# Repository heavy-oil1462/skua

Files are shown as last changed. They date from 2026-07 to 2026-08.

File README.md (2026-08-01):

# Skua

A wind-driven gull scarer for a boat, named for the bird that chases
gulls away. A 1.2 m rotor of flapping plastic flags spins on a
plank-mounted bearing tower; the motion and the clatter keep gulls off.
No electronics, no motor — wind only.

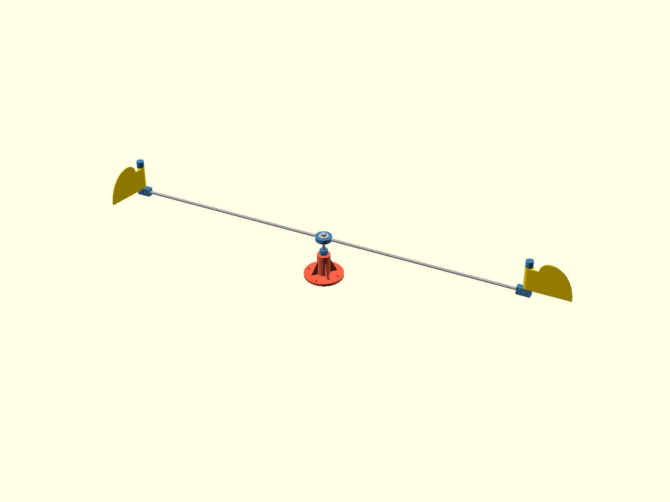
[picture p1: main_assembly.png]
assembly


## How it works

Each vane is a flag on a VERTICAL hinge: a sleeve spinning on a short
vertical stub rod, held at the arm tip by a printed knuckle bracket,
with the panel reaching out sideways like a door. The end cap's stop
wedge rides in a notch in the sleeve's top end and is the vane's only
stop; below, the sleeve rests on a thin PTFE washer on the bracket's
flat top, the vane's whole thrust seat: bought, slippery where a
printed seat drags, and the cheapest wear part there is. The
vane swings freely through about 90 degrees one way and hits the
hard stop the other way, the impact landing flat on the notch walls.
The cap is a clamp, so the driven-stop angle is set, and re-set, by
loosening two bolts — the field-testing knob. The swing angle is the
sleeve notch minus the wedge width, so trying a different swing is a
reprint of two small caps; the vanes do not change. Wind pushing a
vane onto its stop gets the full panel face and drags the rotor
around; wind pushing the other vane (coming back upwind) just
weathervanes it flat. Set both caps the same way around seen from
above so the torques add and the rotor self-starts in any wind
direction. Every pass the driving vane bangs against its stop — free
percussion.

The flag itself is built for the return trip, not the push: catching
wind is the easy half, the swing back to the driven stop is the
fight. So the panel is a thin arched pennant: it spans the sleeve,
runs flat a short shoulder past the sleeve top, rises in a quarter
circle to the arch peak, then sweeps down to the bottom outer tip.
It is a bare 2 mm skin with no stiffening rim, weight being what
the return swing pays for; if a flag ever creep-curls in the sun,
that is the sign to reprint with a slim rim on the arch edge.
Height is free for the
swing mechanics (only the spread over reach enters the hinge
integrals), so the raised arch carries face area near the hinge
where folding wants it, while the shortened reach keeps the tip
inertia the return swing hates low. Compared to the old full
rectangle the hinge inertia drops by more than half and the flappy
free top corner is gone. Nothing of the flag sits close to the end
cap, so the cap's bolt hardware clears the fold at any cap angle.

The hinge being vertical is what makes it start in light wind: folding
never lifts any weight. A vane hanging from a horizontal hinge only
folds when wind pressure beats its weight, roughly a moderate breeze
for printed plastic, and below that both vanes present the same face
and the rotor just rocks. On vertical hinges the returning flag
weathervanes at a whisper, so the asymmetry, and the spin, are there
from the first puff.

The rotor rides on two 608 skateboard bearings spaced 45 mm apart in the
base tower, so the 1.2 m span runs true. All rotating weight hangs on a
collar clamped to the shaft, resting on the top bearing's inner race.

There is also an OPTIONAL uplift retainer: a smaller single-bolt collar
clamped under the bottom bearing, a millimeter clear of its inner race,
living in a cavity inside the base tower. It carries nothing while the
rotor runs, but a wave slam or a gust that unloads the rotor cannot
lift the shaft out of its bearings, and it keeps the bottom bearing
captive. In practice the rotor's weight alone keeps the shaft seated
in all ordinary conditions, so most builds can leave the retainer out;
the shaft is the same length either way, the tip just rides loose in
the cavity, and one can be printed and retrofitted through the open
cavity later if the mooring proves rough (see the assembly guide).

## Bill of materials

- printed: 1 base, 2 hub shells (one part printed twice; they close
  seats to seats over the arms), 2 vanes, 2 tip bracket peg halves +
  2 plain halves (each arm tip clamps between one of each), 2 end
  caps, 1 thrust collar, and optionally 1 retainer collar (see
  `stl/`). Plus one bench tool: 2 die jig halves (again one part
  printed twice), soft vice jaws that hold the shaft for the die
  pass without the vice teeth marking it
- filament: something UV-stable (ASA) for a machine that lives on a
  boat; PLA is fine for prototyping and fit checks but creeps under
  clamp preload and degrades in the sun
- 2x 608 bearing (8x22x7 — any skateboard bearing, shielded preferred)
- 8 mm aluminum rod: 1x 145 mm (shaft), 2x 600 mm (arms), 2x 112 mm
  (the vertical hinge stubs). The arm diameter is a parameter
  (`arm_rod_d`, default 8): thinner arms save weight and the hub
  seats and bracket grooves follow, but re-gauge the arm fit on the
  new stock and let the storm gate judge the arm, which is the
  machine's structural fuse
- 2x PTFE washer 8x14x1 (the vane thrust seats: each sleeve spins on
  one, resting on the bracket's flat top)
- 2x M8 nyloc + 2x M8 fender washer (8.4x30x1.5): the hub clamp.
  The shaft's top end is threaded M8x1.25 for 35 mm with a hand die
  (8 mm rod is an M8 blank; the die self-aligns and nothing is
  drilled), and the washers press the shell sandwich together from
  either end
- 8x M3x25 bolt + nyloc + 1 small washer each (the tip bracket
  clamshells, kept light because they ride at the arm tips; the
  nylocs sit captive in hex pockets, so a screwdriver on the head
  side is the whole tool kit. M3x30s also fit, standing about 5 mm
  proud)
- 6x M3x16 bolt + nyloc (two each for the dual-bolt clamps: the
  thrust collar and 2 caps), plus one more if the retainer is fitted
- 4x 4.2 mm wood screws, and a plank to screw the base onto (any
  thickness, no hole: nothing reaches below the base)

## Calibration before printing the real parts

Printers and filaments vary; the three fits are measured, not guessed.
They are specific to the printer, the slicing profile, AND the
filament: gauges sliced with a different nozzle profile or printed in
a different material do not transfer, so prototyping in PLA and then
building the real machine in ASA means running the gauges again in
ASA with the production profile.

1. Print `stl/bearing_pocket_gauge.stl`, press a bearing into each ring,
   put the number of the firm-but-not-brutal one into `bearing_press_d`
   in `cad/design_params.scad`.
2. Print `stl/rod_fit_gauge.stl`, push the rod through the holes. The
   one it presses into firmly is `rod_snug_d`; the smallest one it spins
   in without grabbing is `rod_free_d`.
3. `python3 scripts/regen_all.py` and print the real parts.

## Assembly

Step-by-step guide with rendered images: [docs/assembly.md](docs/assembly.md).
The short version: bearings pressed into the base; the shaft top
die-threaded (the printed die jig holds it in the vice), then the
hub sandwich built up the thread (nut, washer, shell, arms, shell,
washer, nut), plus the optional retainer clamped flush with the
shaft tip if fitted; the base slid onto the shaft from the tip end,
the thrust collar gauged a millimeter off the top race and clamped,
then everything flipped upright and the base screwed down; the tip
bracket clamshells bolted over arms and stubs, washers, sleeves and
caps slid on, and each cap rotated to its driven-stop angle, both
the same way around, and clamped.
Nothing is drilled anywhere, not the rods, not
the printed parts, not even the plank, and no joint is permanent:
the hub is a washer-clamped sandwich, the tip brackets are
clamshells, everything else is a slit clamp, so every position and
stop angle can be reset by loosening a bolt or two.
Re-torque the clamps at the start of each season, printed plastic
relaxes.

## Alternative versions

Everything above is the default machine, and it is complete as
described. Two alternatives live in the repo, kept current but out
of the main path:

- Hub clamshell (`stl/hub_front.stl` + `stl/hub_back.stl`, plus 5x
  M5x35 bolt + nyloc + 2 wide washers each, replacing the M8 stack
  and the die pass): the pre-sandwich hub, a clamshell that closes
  over shaft and arms and bolts shut. It needs no rod prep at all,
  which is the one reason to choose it; the price is about 80 g and
  three bolts' worth of hardware, and it carries the arms about
  30 mm higher on the same shaft.
- The tri variant ([docs/tri_concept.md](docs/tri_concept.md)): the
  three-arm light-wind sibling of this machine, a parallel line
  with its own release tags (tri-vX.Y), not a successor. It prints
  this exact vane assembly a third time and swaps only the hub for
  a wider three-seat version of the same shell sandwich; `cad/tri/`
  is its home while it matures, and nothing there changes the
  machine on this page.

## Working on the design

CAD is OpenSCAD, rendered headlessly through nix; derived artifacts are
regenerated by one command and gated before commit:

- `python3 scripts/regen_all.py` after any .scad change
- `python3 scripts/regen_all.py --check` before any commit

The gates cover interface dimensions (`check_params.py`), the assembly
stack-up (`geometry_check.py`), and performance (`performance_check.py`:
the wind speed the rotor spins up at, a parasitic drag ratchet, and
storm-case safety factors for every load path). CI runs the same
command, so a change that would not fit, not start, or not survive
does not merge.

See `CLAUDE.md` for the full workflow and design rules.

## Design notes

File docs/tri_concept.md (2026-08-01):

# The tri variant: consistent spin in the least wind

Skua ships in two parallel variants, each with its own release line
tagged on main:

- the DUAL: two arms, solid vanes, the mature machine (v1.0 at tag
  time). Its docs are the README and the assembly guide.
- the TRI: three arms, the light-wind variant, young (tri-v0.1
  when it first flies). This document and `cad/tri/` are its home
  while it grows; it is a sibling of the dual, not its successor,
  and both live on.

Status: concept study. Nothing under `cad/tri/` changes dual parts,
parameters or gates, and nothing from it is exported to `stl/`.

One constraint carries over from the dual: the overall span stays
close to today's sweep circle, so when vane reach grows the arms
shorten to match. Everything else is open.

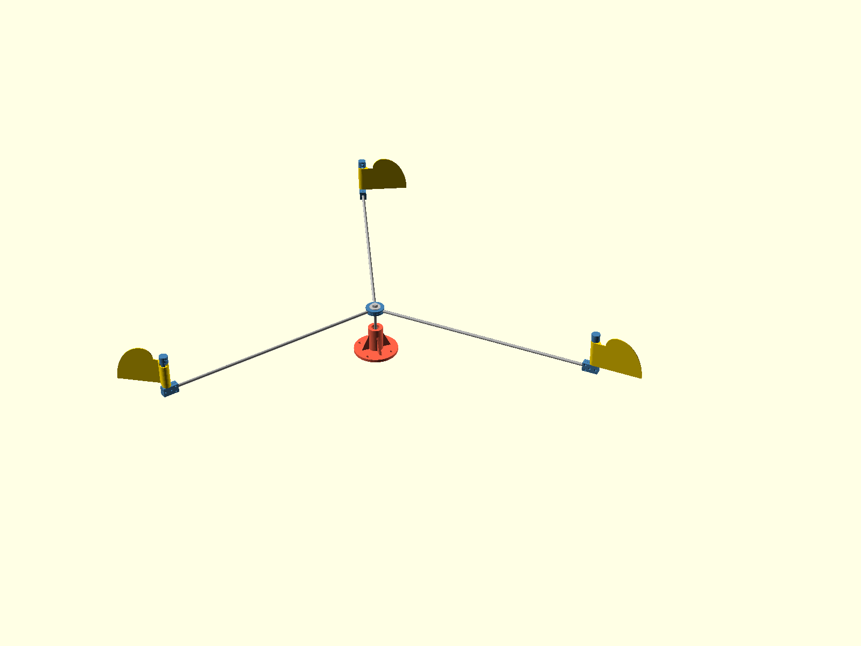
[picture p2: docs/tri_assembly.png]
tri concept


The scene is `cad/tri/tri_assembly.scad`; open it in OpenSCAD to
walk around it (regen_all renders it to the image above). It shows
the tri as currently planned: the ENTIRE vane assembly, tip
bracket, stub, PTFE thrust washer, vane and cap-wedge stop, is the
dual's verbatim, printed and bought once more per extra arm. Only
the hub is the tri's own (its wider washer-jaw sizing lives in
`tri_` prefixed parameters), and nothing from `cad/tri/` is
exported to `stl/`.

The recipe is deliberately minimal: the only new joint is the hub,
and the only rod prep in the whole machine is one M8x1.25 die pass
on the shaft's top end (8 mm rod is an M8 blank, so a hand die
self-aligns; no drilling, no taps, no lathe). A third vane-arm set
from the dual's own STLs plus the hub hardware turn dual spares
into a tri rotor, and every spare fits both machines.

## The washer-jaw hub

The hub is the shell sandwich (`tri_hub_shell` in
`cad/tri/tri_hub.scad`, the one in the scene): the same design the
dual runs as its default hub (`cad/hub_shell.scad`), sized for
three seats at 120 degrees, so the one hub design serves both
machines the way the one vane assembly does. Two identical thin
half-shells, each a half-round seat over a web, cradle the arms
over the full grip; the arms butt the boss circle and stand proud
of the mating faces by half the clamp gap, and two large M8 fender
washers press the sandwich together, clamped by M8 nylocs on the
shaft's die-threaded top end (8 mm rod is exactly an M8 thread
blank, so a hand die self-aligns and this rod is never drilled at
all; the lower nut is the shoulder, run to the die's thread
runout, and the upper one is the clamp). The arms get distributed
bearing top and bottom, nothing can rattle, and field seasons on
the dual proved the design out. The webs put a little plastic in
the clamp path, so the hub nuts join the seasonal re-torque round.

An alternative sits alongside it in the same file
(`tri_hub_disc`): ONE printed spacer disc, thinner than the rod,
three full-height slots keying the arms, the fender washers
pressing directly onto the rods from either side. Its load path is
worth stating: steel washer, aluminum rod, steel washer, steel
nut. No plastic sits in compression anywhere in that joint, so
unlike every clamp on the dual it does not relax and never needs
the seasonal re-torque; the price is that the washer rims
edge-clamp the arms instead of cradling them, and the slot flanks
alone carry the arms' horizontal storm bending. Same hardware,
one part instead of two, 7 mm tall against 13. The sandwich is the
default; the disc stays modeled for an A/B on the water if the
re-torque round ever grates.

A structural note, recording a correction: an earlier pass
rejected male thread on the shaft, claiming the storm case fails
at the threaded exit with a safety factor near 0.7. That number
was wrong, it borrowed the ARM's root moment (about 5.8 Nm). The
shaft at the hub only carries the vane drag over the short lever
down to the top bearing, about 1 Nm at survival wind, so even on
the M8 minor section the stress is about 42 MPa against the
alloy's 160: a storm factor near four, with gust amplitudes far
below fatigue concern. The storm-critical member is and remains
the arm, unaffected by any hub choice.

Sourcing notes for the prepared rods, kept from earlier rounds:

- Tube cannot be tapped: any 8 mm tube has a bore at or above 5
  mm, already larger than the M5 thread. Solid rod only.
- Solid 8 mm rod taps easily by hand (center punch, drill 4.2 mm
  about 14 mm deep, tap M5x0.8), and dies easily by hand (chamfer
  the end, run the die). Concentricity is not critical in either
  case, because bores and steps locate the rods and the threads
  only supply axial preload.
- For kits, linear-motion suppliers sell ground 8 mm shafts with
  threaded ends as a standard catalog option, which is zero
  machining.

## Dropped directions, recorded so they stay dropped

The tri once carried its own vane-assembly variants: a keyed stop
ring with a fin (angle baked into a bracket pocket, no
set-at-assembly step), a wedge-free clamp cap, a bottom-notched
vane, and a deferred screwed-stub tip (stubs tapped both ends,
pulled home by M5s, the direction a commercial kit might take).
All of it was deleted when the tri adopted the dual's vane
assembly wholesale. The reasons, so nobody re-derives the parts:
one part set now serves both machines (every printed spare fits
either rotor), the taps stay out of the toolchain, and the dual's
field seasons showed the adjustable cap stop is the knob you
actually want on the water, worth its price of hand-setting the
caps to a common sense — a price the tri pays once more per extra
arm. The keyed-stop idea itself was sound and lives in git
history if a kit round ever wants it back.

What the tri needs, beyond printed parts and rod stock: the hub's
two M8 nylocs with fender washers, and the dual's own tip
hardware three times over (four M3x25 per bracket clamshell, two
M3x16 per cap, two more at the thrust collar). Rod prep is the
single die pass on the shaft. The arms butt the hub's boss
circle; the set-by-hand joints are the gauged thrust collar and
the three cap wedges, same sense seen from above so the torques
add.

The dual's performance work showed what limits low-wind running
once the geometry is tuned: thrust-seat friction, vane mass, and
the two-arm torque gap. `scripts/tri_study.py` models the candidate
fixes as a cumulative ladder; run it for current numbers. The
directional findings:

- The worst parking angle of the two-arm rotor produces NEGATIVE
  torque (the wind holds it against rotation), which is the rocking
  behavior seen at low wind. Three arms at 120 degrees turn the
  worst angle into about 0.7 of mean torque; this is the single
  biggest consistency change and needs a new hub, a third arm and a
  third vane, nothing else.
- The PTFE thrust washer, once a tri ladder rung, is the dual's
  own baseline seat now. Film-and-frame vanes (printed perimeter,
  mylar or ripstop skin, ~28 g against 78) are the next real rung:
  they cut self-start sharply and also fix the re-arm margin (run
  the study for current numbers).
- Holding the span while trading arm length for vane reach (500 mm
  arms, 250 mm reach) needs 10 mm arm rod, abandoning the dual's
  one-rod-stock rule, and lands self-start around 0.26 m/s with a
  better storm margin than the dual has today.
- A meter more tower height is worth about ten percent of wind at
  threshold from the boundary layer alone.

Rejected endpoint, recorded so it is not rediscovered: cup or
Savonius geometry spins earliest of all but loses the flapping and
the clack that actually scare gulls; a rotation-driven clacker
would have to be bolted on, at which point the swing-vane concept
is the simpler machine.

Build order as the tri matures toward its first release: three
arms first via the washer-jaw hub above (pure consistency, dual
vanes throughout), then washers, then film vanes, then the
reach-for-arm trade only if the water still asks for it. Further
tri ideas land here as they come.

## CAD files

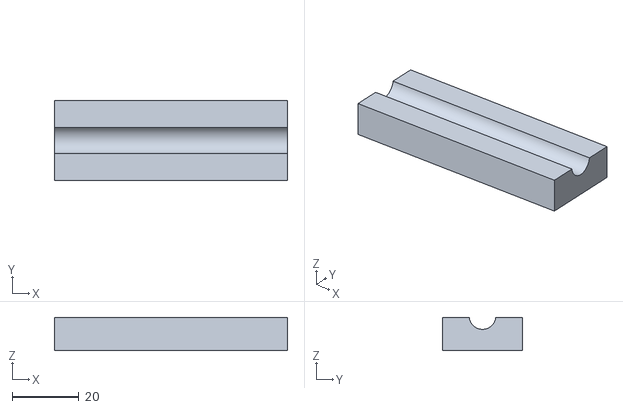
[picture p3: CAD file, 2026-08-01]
stl/die_jig.stl
70.0 x 24.0 x 10.0

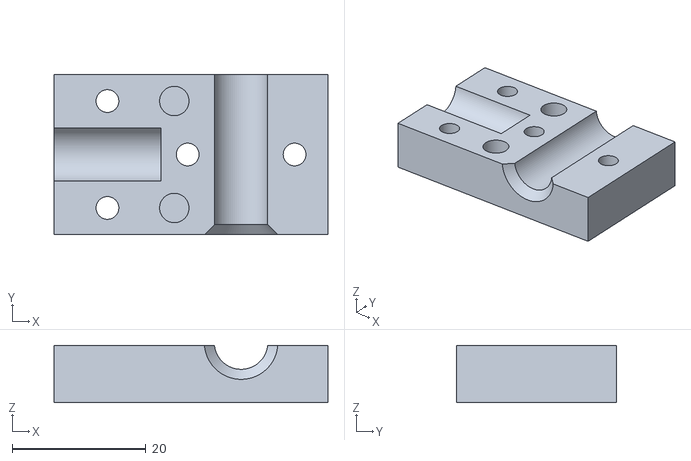
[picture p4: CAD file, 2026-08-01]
stl/bracket_plain_half.stl
41.0 x 24.0 x 8.60

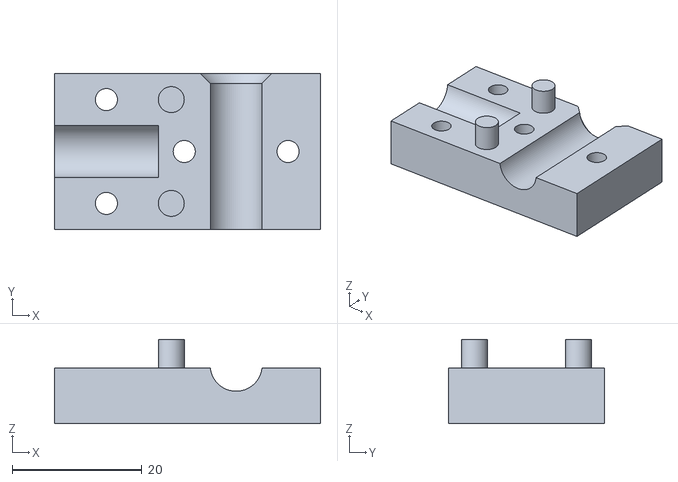
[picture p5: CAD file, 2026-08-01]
stl/bracket_peg_half.stl
41.0 x 24.0 x 13.0

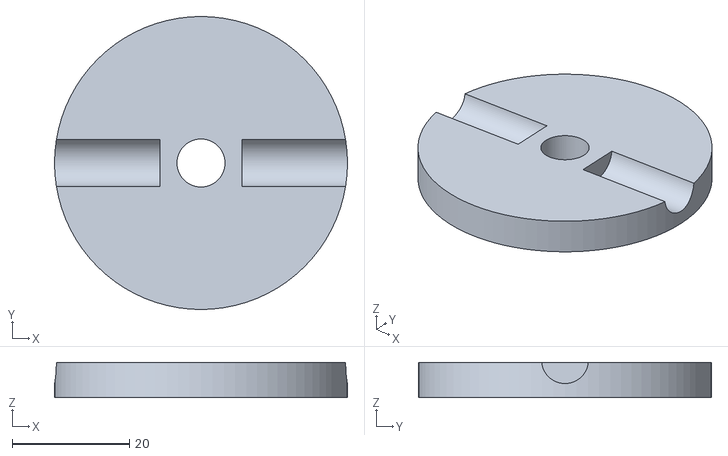
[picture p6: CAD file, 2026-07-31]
stl/hub_shell.stl
50.0 x 50.0 x 6.00

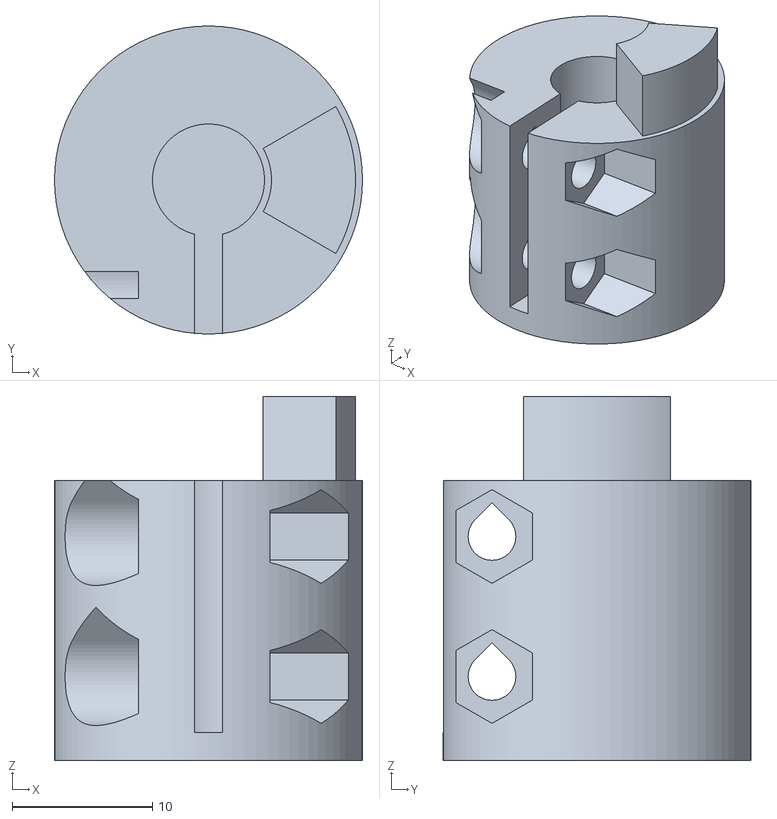
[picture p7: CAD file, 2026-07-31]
stl/end_cap.stl
22.0 x 22.0 x 26.0

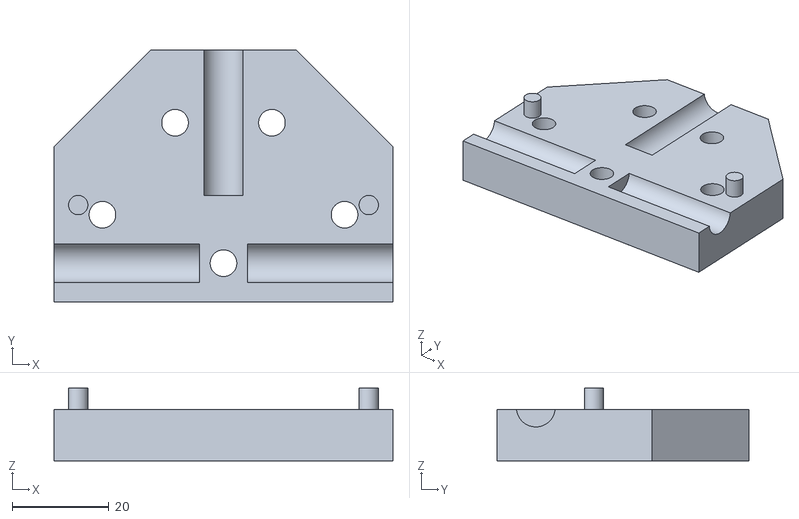
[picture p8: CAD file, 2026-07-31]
stl/hub_front.stl
70.0 x 52.0 x 15.0

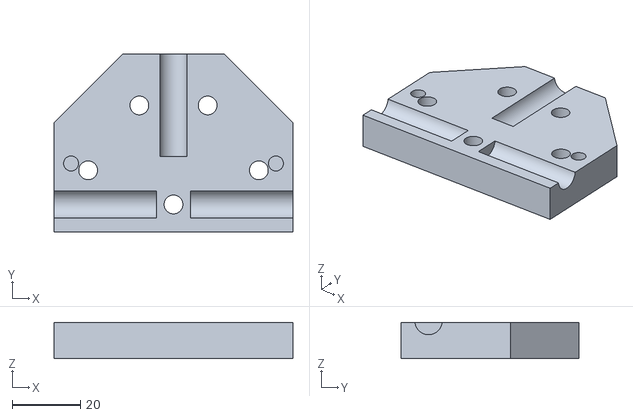
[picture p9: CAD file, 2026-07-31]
stl/hub_back.stl
70.0 x 52.0 x 10.6

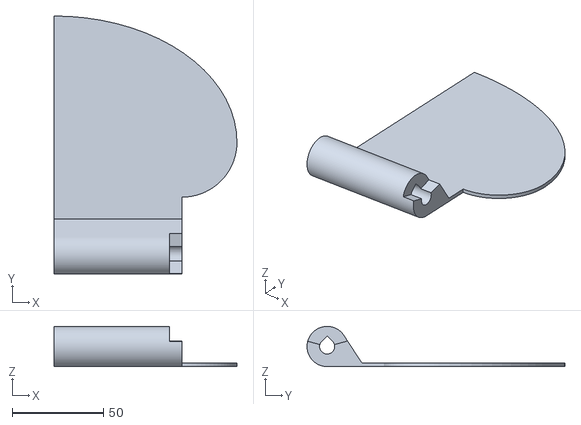
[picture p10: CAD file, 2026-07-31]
stl/vane.stl
100.0 x 141.0 x 22.0

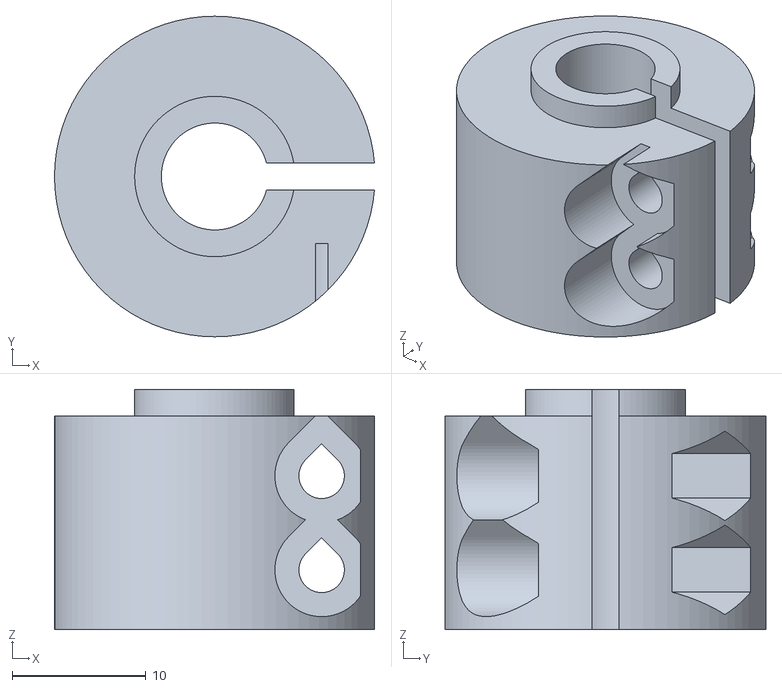
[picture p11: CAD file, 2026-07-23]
stl/collar.stl
24.0 x 24.0 x 18.0

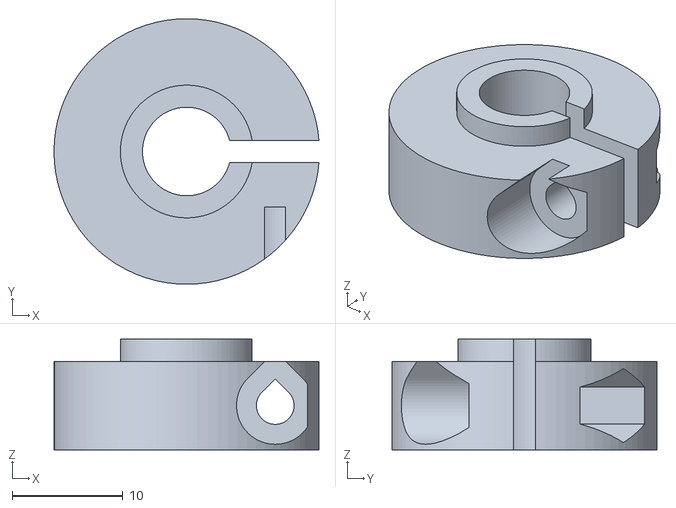
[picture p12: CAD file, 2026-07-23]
stl/retainer.stl
24.0 x 24.0 x 10.0

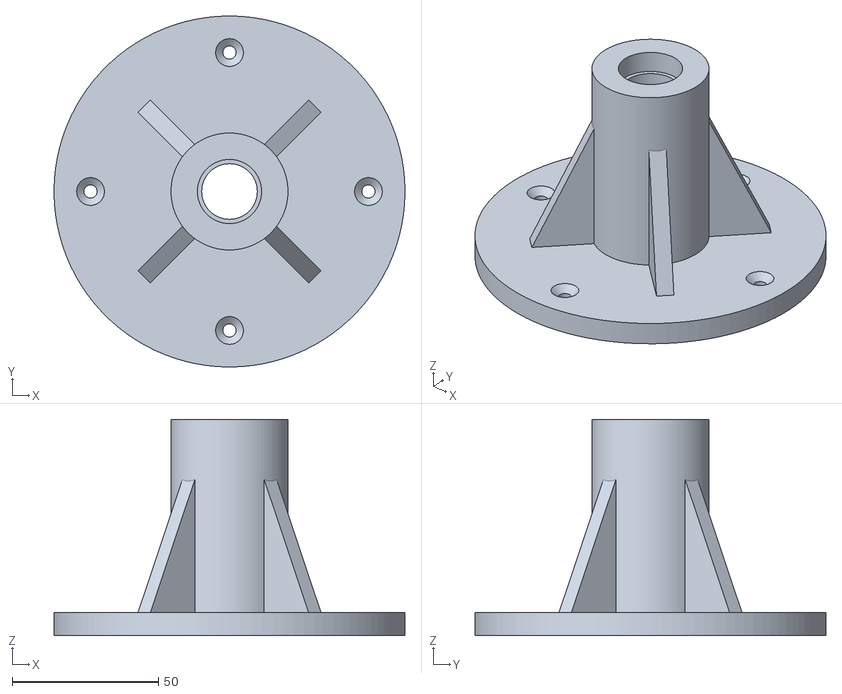
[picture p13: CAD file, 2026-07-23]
stl/base.stl
120.0 x 120.0 x 74.0

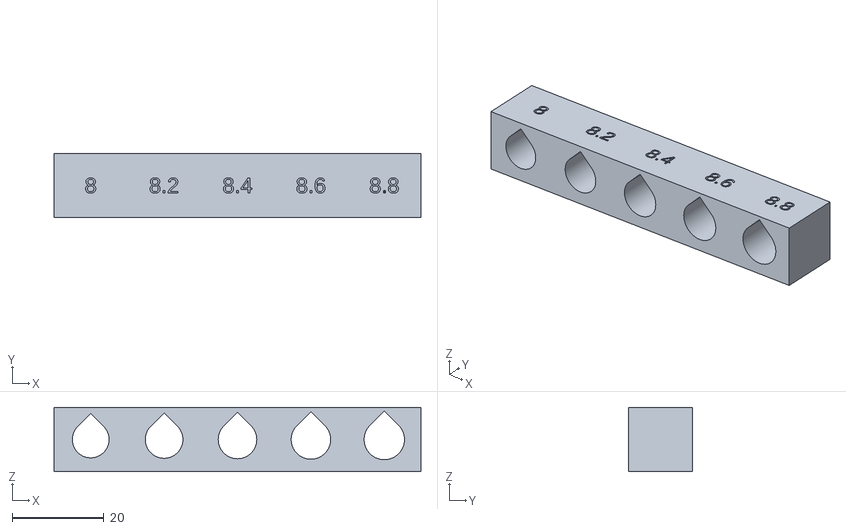
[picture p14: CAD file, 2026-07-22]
stl/rod_fit_gauge.stl
80.0 x 14.0 x 14.0

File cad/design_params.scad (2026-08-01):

// ============================================================
// SKUA SHARED DESIGN PARAMETERS — single source of truth for
// every dimension two parts must agree on.
//
// Consumers:
//   - every part in cad/ does        include <design_params.scad>
//   - parts in cad/calibration/ do   include <../design_params.scad>
//   - scripts/check_params.py FAILS the build if any of these names
//     is re-declared anywhere else — change values HERE only.
//
// Keep this file to simple `name = value;` lines so the tooling can
// parse it. One-off experiments: `openscad -D name=value` beats the
// include, no need to edit this file.
// ============================================================

// --- Aluminum rod stock (bought) ---
// 8 mm rod matches the 608 bearing bore, so shaft and stubs are
// PINNED to it (and the hub disc variant's M8 die pass rides on it).
// The arms default to the same stock but have their own knob below:
// thinner arms are a weight experiment, and the storm gate decides
// (the arm is the machine's fuse — watch its SF when thinning).
rod_d        = 8;
arm_rod_d    = 8;    // the two horizontal arms ONLY. Changing it
                     // (say to 6) resizes the hub shell seats and
                     // the bracket arm grooves; re-gauge arm_snug_d
                     // on the new stock first (the rod fit gauge
                     // grows a second bar when this differs from
                     // rod_d; the seat depth follows the gauged fit,
                     // and geometry_check gates the shell web left
                     // under it)
shaft_length = 145;  // vertical shaft; sets how high the rotor rides.
                     // Long enough that the hanging vanes clear the
                     // plank (geometry_check.py gates the clearance)
                     // and that the tip reaches down through the
                     // uplift retainer inside the base cavity.
arm_length   = 600;  // each horizontal arm (two of them)
stub_length  = 112;  // the vertical hinge rod at each arm tip (two of
                     // them, same stock): clamped through the tip
                     // bracket, carrying the vane sleeve and its cap
                     // (112 since the sleeve seat became the 1 mm PTFE
                     // washer; the old ring boss stood 2 mm)

// --- 608 skateboard bearing (bought, TWO of them) ---
// Two bearings spaced apart in the base tower instead of one: a single
// 7 mm-wide bearing lets a 1.2 m rotor wobble; two races 45 mm apart
// make the shaft run true. They come in packs of 8 anyway.
bearing_od = 22;
bearing_w  = 7;
bearing_inner_shoulder_d = 12;  // inner-ring shoulder: anything riding
                                // the INNER race (collar boss) stays
                                // inside this; anything static stays
                                // outside it
pocket_recess = 0.5;  // bearings sit this far below the tower faces so
                      // the rotating inner race never rubs plank or collar body

// --- Calibrated fits (print the gauges, type the winners in here) ---
bearing_press_d = 21.95; // pocket that grips the outer race — cad/calibration/bearing_pocket_gauge.scad
rod_snug_d      = 8.0;  // sockets the rod presses into (hub, collar, cap) — cad/calibration/rod_fit_gauge.scad
rod_free_d      = 8.2;  // bores that must SPIN on the rod (vane sleeve) — same gauge
arm_snug_d      = 8.0;  // grooves the ARM presses into (hub, bracket,
                        // disc slots) — same gauge, arm bar. MEASURED,
                        // never derived: while arm_rod_d == rod_d this
                        // must equal rod_snug_d (geometry_check pins
                        // it); on other arm stock, gauge that stock
fit_tol         = 0.2;  // clearance for printed slots/pockets

// --- Base (screwed to the plank) ---
base_d         = 120;
base_t         = 8;
screw_hole_d   = 4.5;   // 4.2 mm wood screws
screw_head_d   = 9.5;   // countersink cone top diameter
screw_circle_d = 95;
screw_count    = 4;
tower_od       = 40;    // 9 mm wall around the bearing pockets
tower_h        = 74;    // top bearing pocket at the top; the bottom
                        // pocket sits base_cavity_h up, above the
                        // retainer cavity, keeping the races 45 mm apart
tower_bore_d   = 19;    // between the pockets: retains the outer races,
                        // clears the 12 mm inner-race shoulders
gusset_t       = 6;
gusset_reach   = 25;    // how far a gusset runs out from the tower wall
gusset_h       = 55;

// --- Hub clamshell VARIANT (hub.scad, optional alternative to the
//     sandwich below for a build that skips the die pass) ---
// A CLAMSHELL: split on the vertical plane that contains all three rod
// axes, so the two halves close over the rods like a pillow block and
// five M5 bolts with wide washers clamp everything at once. No hole is
// drilled in any rod at the hub, which is where rod bending is worst.
// Was the default until the washer-jaw sandwich took over: it needs
// no rod prep at all, at the price of five M5s and about 80 g. The
// arm station rides about 30 mm higher than the sandwich puts it,
// on the same shaft.
hub_len          = 70;  // along the arms
hub_w            = 22;  // across the split: each half is a groove
                        // (4) plus backing wall (7); the clamp
                        // preload is bolt-and-washer, not wall
hub_h            = 52;
hub_arm_z        = 44;  // arm bore axis above the hub bottom face
hub_shaft_socket = 30;  // blind shaft socket depth, from the bottom
hub_arm_socket   = 30;  // blind arm socket depth, from each end
                        // (still well past the bracket's 22 grip)
hub_beam_z       = 28;  // T profile: below this only the stem and its 45
hub_stem_w       = 30;  // degree chamfers remain — the lower corners of
                        // the old box carried no load and cost print time
hub_clamp_gap    = 0.8; // total gap between the closed halves: the rods
                        // stand proud of their grooves by this much, so
                        // bolt preload lands on the rods, never on
                        // face-to-face plastic
hub_bolt_stem_x  = 10;  // M5 clamp bolts: two flanking the shaft groove
hub_bolt_beam_x  = 25;  // ... two under the beam, outboard ...
hub_bolt_beam_z  = 34;  // ... plus one through the center web at arm
                        // height; geometry_check verifies every wall
hub_peg_x        = 30;  // registration pegs, so the bolts never carry
hub_peg_z        = 32;  // the job of aligning the halves
hub_peg_d        = 4;

// --- Hub sandwich (hub_shell.scad, THE hub; print TWO of the one
//     part): the tri's shell hub sized for two arms. Two identical
//     thin half-shells cradle the arms in half-round seats, arms
//     butted against the boss circle and standing proud of the
//     mating faces by half the clamp gap, so the shells never
//     touch; two M8 fender washers press the sandwich together
//     from either end, clamped by M8 nylocs on the shaft's
//     die-threaded top end. Full-length seats bear kindly on the
//     arms and nothing can rattle; the webs put a little plastic
//     in the clamp path, so the M8 nuts join the seasonal
//     re-torque round. About 80 g lighter than the clamshell plus
//     its M5 hardware, at the price of the one rod prep in the
//     build (a hand die on the shaft top, still no drilling) and
//     an arm station about 30 mm lower on the same shaft ---
hub_shell_d      = 50;  // seats run boss to rim: 18 mm of bearing
                        // per arm for horizontal storm bending
hub_shell_h      = 6;   // one half-shell: the half-seat (arm_snug_d/2
                        // minus half the clamp gap, cut in the scad)
                        // plus the web under it (geometry_check
                        // gates the web that remains)
hub_shell_boss_d = 14;  // arm butt circle around the free bore
hub_shaft_thread = 35;  // M8x1.25 die length on the shaft top: the
                        // nut-washer-sandwich-washer-nut stack plus lead
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

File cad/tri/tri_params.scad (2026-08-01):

// ============================================================
// SKUA TRI VARIANT PARAMETERS — study values only, tri_ prefixed so
// nothing shadows design_params.scad (check_params enforces that).
//
// The tri keeps the dual's ENTIRE vane assembly verbatim (bracket,
// stub, PTFE seat, vane, cap-wedge stop; three caps hand-set to
// the same rotational sense instead of two) and changes only the
// count and the hub sizing: three arms at 120 degrees in its own
// wider washer-jaw hub from tri_hub.scad. The later ladder steps
// from scripts/tri_study.py (film vanes, the reach-for-arm trade)
// keep their values below.
// ============================================================

tri_arms       = 3;    // the consistency fix: no dead parking angle

// --- Washer-jaw hub (tri_hub.scad): one printed spacer disc keys
//     three arms in full-height slots; two large fender washers
//     press onto the proud rods from either side, clamped by M8
//     nylocs on the shaft's die-threaded top end. Steel jaws, no
//     plastic in compression, no seasonal re-torque ---
tri_hub_d        = 50;   // slot flanks run boss to rim: 18 mm of
                         // bearing per arm for horizontal bending
tri_hub_disc_h   = 7.2;  // rod_d minus the clamshell gap: the arms
                         // stand proud of both faces by 0.4, so the
                         // washer preload lands on the rods, never
                         // on face-to-face plastic
tri_hub_boss_d   = 14;   // arm butt circle around the bore
tri_hub_gap      = 0.8;  // clamshell rule: the rods stand proud of
                         // their seats or slots by half this per
                         // side, so preload lands on the rods
tri_hub_shell_h  = 6;    // the sandwich variant's half-shell: a
                         // 3.6 half-seat plus a 2.4 web under it
tri_shaft_thread = 40;   // M8x1.25 die length on the shaft's top end
                         // (rod prep: a hand die, no drilling at
                         // all). The nut and fender-washer sizes are
                         // the shared m8_* values in design_params
                         // (the dual's hub sandwich uses the same
                         // jaw stack)

// --- Later ladder steps (tri_study.py's numbers; NOT in the v0.1
//     scene, which uses the dual's rod_d / arm_length / vane) ---
tri_arm_rod_d  = 10;   // reach-for-arm trade only; arm rod, never stubs
tri_arm_length = 500;  // span held: shorter arms buy the longer reach
tri_vane_reach = 250;  // film vane reach (dual: 150)
tri_frame_w    = 8;    // printed perimeter frame member width
tri_frame_t    = 4;    // ... and thickness
tri_frame_h    = 140;  // film vane frame height (the dual's old
                       // full-height panel; the dual itself moved
                       // to the arched pennant with no height
                       // param). Keep in sync with FILM_FRAME_H in
                       // scripts/tri_study.py, which cannot read
                       // this file
tri_skin_t     = 0.4;  // membrane, drawn translucent (the PTFE
                       // washer on the ring boss is the shared
                       // ptfe_washer_* part in design_params, the
                       // dual's thrust seat)
tri_mast_h     = 300;  // the taller mounting, study numbers only,
                       // not drawn (the ladder credits ~10 percent
                       // wind for +1 m)

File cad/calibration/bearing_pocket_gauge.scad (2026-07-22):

// BEARING POCKET GAUGE — dials in the 608 press fit before printing the
// whole base.
//
// One print gives three rings, each bored to a different candidate
// bearing_press_d and engraved with that number. Press a bearing into
// each: keep the one that takes a firm thumb/vise push and does not
// rock, then put ITS number into bearing_press_d in
// cad/design_params.scad — both base pockets export from that value.
//
// If the best fit is one of the outer rings the truth is outside the
// bracket: move bearing_press_d to that number and reprint to bracket
// it again. Recalibrate when changing filament or printer.

include <../design_params.scad>
include <../lib/labels.scad>

variant_count = 3;
variant_step  = 0.15;
ring_gap      = 8;
label_size    = 4;
label_depth   = 0.8;

$fn = 128;

wall  = (tower_od - bearing_od) / 2;
ring_h = bearing_w + 2;

function variant_d(i) = bearing_press_d + (i - (variant_count - 1) / 2) * variant_step;

module pocket_ring(d) {
    outer_r = d / 2 + wall;
    difference() {
        cylinder(h = ring_h, r = outer_r);
        // pocket depth as in the base: a real shoulder to press against
        translate([0, 0, ring_h - bearing_w - pocket_recess])
            cylinder(h = bearing_w + pocket_recess + 0.1, d = d);
        translate([0, 0, -0.1])
            cylinder(h = ring_h + 0.2, d = tower_bore_d);
        translate([0, 0, ring_h / 2])
            curved_text(str(d), outer_r, label_size, label_depth);
    }
}

pitch = bearing_od + 2 * wall + variant_count * variant_step + ring_gap;

for (i = [0 : variant_count - 1])
    translate([(i - (variant_count - 1) / 2) * pitch, 0, 0])
        pocket_ring(variant_d(i));

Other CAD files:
cad/calibration/rod_fit_gauge.scad
cad/base.scad
cad/bearing_608.scad
cad/bracket_peg_half.scad
cad/bracket_plain_half.scad
cad/collar.scad
cad/die_jig.scad
cad/end_cap.scad
cad/hub.scad
cad/hub_back.scad
cad/hub_front.scad
cad/hub_shell.scad
cad/main_assembly.scad
cad/retainer.scad
cad/stop_ring.scad
cad/tip_bracket.scad
cad/tri/film_vane.scad
cad/tri/tri_assembly.scad
cad/tri/tri_hub.scad
cad/vane.scad

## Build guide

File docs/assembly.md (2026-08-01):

# Assembly guide

What you need at the bench: the printed parts (see the BOM in the
README), the two 608 bearings, the five rod pieces (1x 145 mm, 2x
600 mm, 2x 112 mm of 8 mm aluminum), the two PTFE washers (8x14x1,
the vane thrust seats), an M8x1.25 hand die with its stock, a vice
and the two printed die jig halves to hold the shaft in it, the two
M8 nylocs and fender washers for the hub, the M3 bolts with nyloc
nuts, four wood screws, screwdrivers or hex keys to suit, a 13 mm
wrench or socket for the M8 nuts, and, only if you fit the optional
retainer, something about 1 mm thick and no wider than about 15 mm
(a strip of folded business card, a feeler gauge) for gauging the
thrust collar. Nothing is drilled in the whole build: not the rods,
not the printed parts, and not the plank either. The one rod prep is
the die pass on the shaft top in step 2.

Three joint types cover the whole build, and all are clamps. The hub
is a sandwich: two identical printed shells cradle the arms and two
M8 nuts squeeze the stack between fender washers on the shaft's
die-threaded top. The tip brackets are clamshells: lay the rods into
the grooves and bolt the halves together with washered M3s. The
collars and end caps are wide slit clamps, each closed by two M3
bolts crossing the slit: slide to position, set the angle, tighten
both bolts. Every joint stays re-adjustable by loosening a nut or
two, and the flip side of friction everywhere is maintenance:
re-torque every clamp bolt, the hub nuts included, at the start of
each season, because printed plastic relaxes.

The images regenerate from the CAD via `python3 scripts/regen_all.py`
(they are `cad/main_assembly.scad` rendered at `-D step=N`), so they
always match the current parameters.

## 1. Base and bearings

Press one bearing into the pocket on top of the tower, flush to its
recess floor. The bottom pocket sits up inside the tower, above the
retainer cavity: turn the base over, drop the bearing into the
cavity, and press it up until it seats against the pocket ceiling.
Push on the OUTER race only; a spare 608 from the pack, held flat on
top, makes a good drift. If either fit fights you, recheck
`bearing_press_d` with the calibration gauge instead of forcing it.

Do NOT screw the base to the plank yet. The shaft and its retainer
enter the cavity from below, so the base meets the plank only at the
end of step 3, with the rotor already in it.

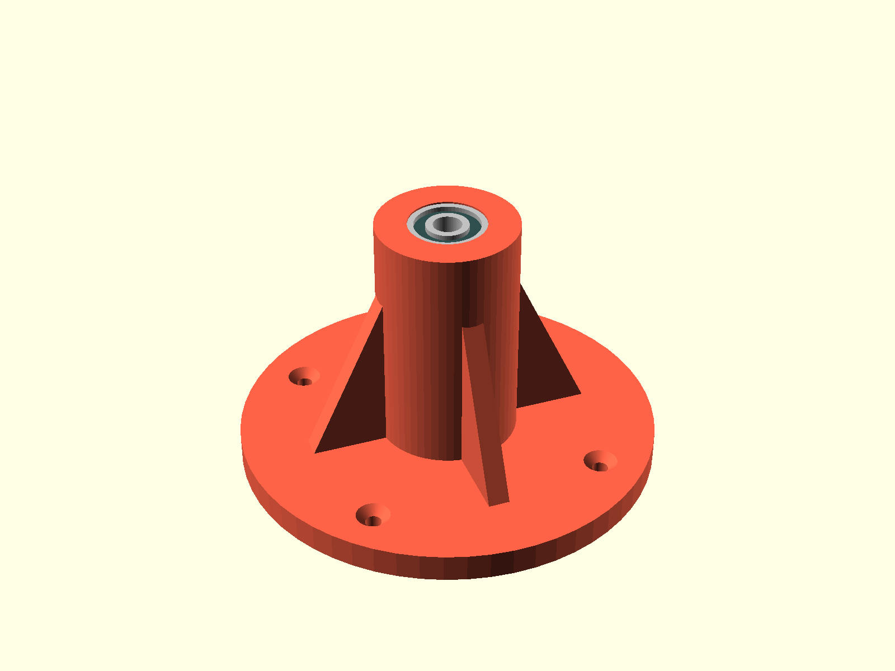
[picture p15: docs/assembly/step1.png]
step 1


## 2. Rotor core on the die-threaded shaft top

This all happens on the bench, and nothing is drilled. First the one
rod prep of the build: run the M8x1.25 die 35 mm down the shaft's
top end. Hold the shaft with the printed die jig: lay it into one
half's groove, close the second half over it (they are the same
part), and clamp the pair in the vice with the top end standing up
and the blocks' flat backs against the jaws. The grooves grip the
rod over their whole length, so the vice can pull properly hard
without its teeth marking the rod, and like every clamshell in this
machine the halves must not touch: an even gap between the blocks
means the rod is gripped. An 8 mm rod is an M8 thread blank, so the
die self-aligns; a drop of oil and a quarter turn back per turn
forward and it cuts clean. Then slide the thrust collar (the wide plain one, no wedge)
onto the shaft from the other end and leave it loose: it cannot pass
the hub nuts later, so it must be on the shaft now. The small
single-bolt retainer goes on at the end of this step, at that same
tip end.

Now build the hub sandwich up the thread: spin the first nyloc down
until it stops where the thread runs out, then a fender washer, then
one shell seats UP. Lay both 600 mm arms into the seats and push
them inward until they butt the shaft, which guarantees both arms
reach equally far. Close the second shell over them seats DOWN (the
two shells are the same part; the arms key them, no pegs needed),
add the second washer, and tighten the top nyloc with the 13 mm
wrench while a second wrench holds the bottom nut. Tight is right:
the nuts bear on steel washers, so give it a proper wrench torque,
not just finger feel.

The shells must NOT touch when tight: the seats are shallower than
half the arm, so the arms hold the shells about 0.8 mm apart and
all the nut force squeezes the rods. An even gap all around means
the arms are gripped; faces touching anywhere means something is
not seated. The top nut lands about flush with the shaft tip when
the stack is right.

Last, the retainer, and this one is OPTIONAL: the rotor's weight
alone keeps the shaft seated in its bearings in all ordinary
conditions, so most builds skip it and add it later only if the
mooring proves rough (how, at the end of step 3). The shaft is the
same length either way. To fit it now: slide the small single-bolt
collar onto the shaft tip, boss first (boss toward the hub), and
push it flush with the tip. Easiest is to stand the tip on the bench
so tip and collar press flat against the same surface, then tighten
the bolt. Flush is the whole trick: it needs no measuring, and it is
the reference that makes the next step work.

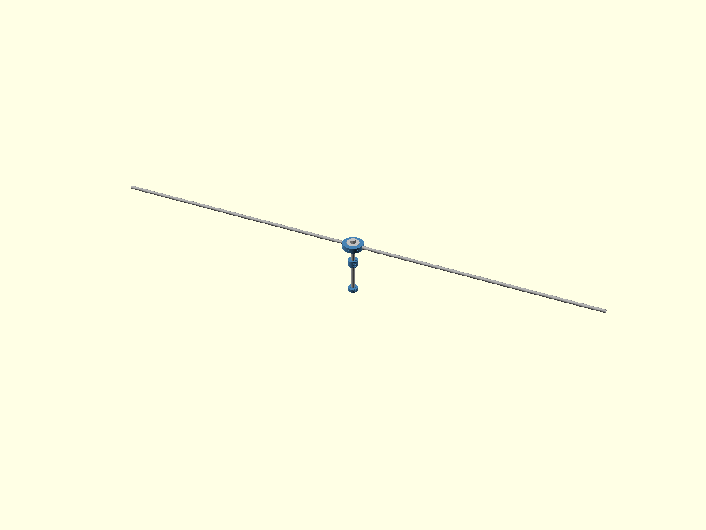
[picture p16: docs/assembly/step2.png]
step 2


## 3. Mate rotor and base, gauge the gap, screw down

Turn the rotor upside down: top hub nut on the bench, shaft pointing
up, bare arms out over the bench edges. Lower the base over the
shaft, tower top first: the shaft threads through both bearings, the
retainer disappears into its cavity, and the base comes to rest with
the bottom bearing's inner race sitting on the retainer boss.
Gravity does the aligning, and that resting contact is exactly the
uplift catch, which is what makes the next move exact.

Now gauge the running clearance, with everything out in the open:
the thrust collar hangs loose on the shaft by the tower top. Lay the
1 mm card strip on the top bearing's inner race (it must be narrow
enough to sit down on the race, inside the pocket mouth, not on the
plastic rim), push the collar boss against it, and tighten the two
clamp bolts evenly. The whole rotor will hang on this collar, so
give its bolts a deliberate, even torque, then pull the strip out.

That card thickness is exactly the play the shaft ends up with: flip
the assembly upright and the rotor settles onto the thrust collar,
leaving the retainer floating 1 mm under the bottom race, touching
nothing, ready to catch the inner race if a wave or a gust unloads
the rotor. Set the base on the plank and drive the four wood screws.
The shaft can never lift out and the bottom bearing is captive. To
re-torque the retainer bolt at season start, take out the four wood
screws and reach into the open cavity from below; every other bolt
is in the open.

Building WITHOUT the retainer: same upside-down mating, but there is
nothing for the base to rest on and no gap to gauge. Lower the base
until the tip sits a few millimeters down inside the cavity (the
cavity mouth faces up in this pose, so you can see the tip in it),
hold the base there, seat the thrust collar directly on the top race
with no card, and clamp. Flip, screw down, done; the tip just rides
loose in the cavity.

Adding the retainer later: print one, take out the four wood screws,
and lay the whole machine on its side. Slide the retainer through
the open cavity mouth onto the tip, boss toward the bearing, push it
to 1 mm short of the bottom race with the card strip between boss
and race, and tighten its bolt through the mouth. Stand it up and
screw it back down.

The image below shows the base cut open so the collars and the
retainer are visible; yours is in one piece.

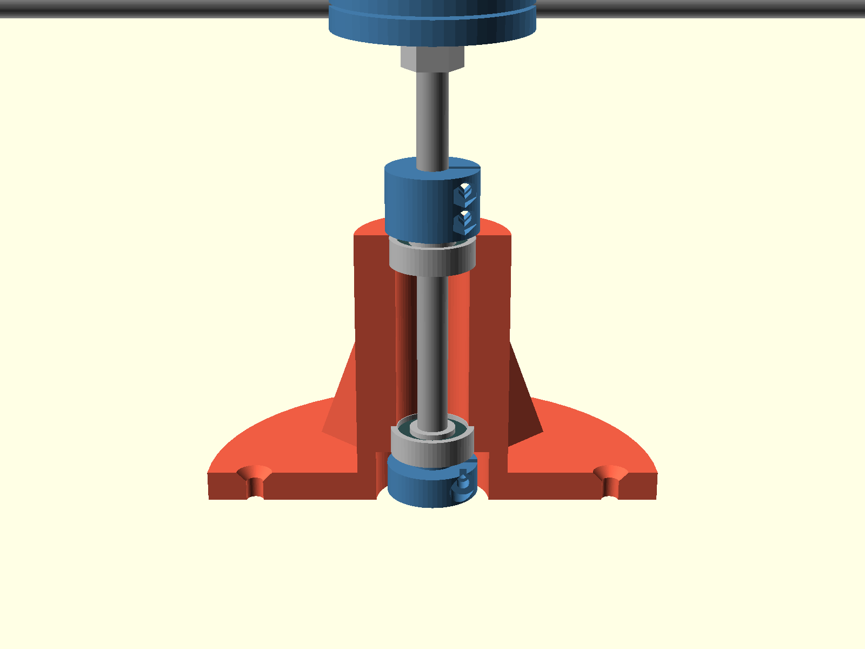
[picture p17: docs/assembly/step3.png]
step 3


## 4. Tip bracket clamshells, stubs, vanes

Each tip bracket is two printed halves that close over the arm and
the stub the way the hub shells close over the arms: the PEG half
and the PLAIN half (the peg sockets). Nothing needs to be juggled in
mid-air here: the stub groove runs straight through the bracket
with a funnel mouth at its top face, so the clamshell closes over
the arm alone and the stub feeds in from above afterward.

Lay the peg half groove side up and set the arm end into the long
groove until it bottoms out. Fit the plain half over the pegs,
press a nyloc into each of the four hex pockets in the plain
half's outer face, and add the four M3x25s with a small washer
under each head, but leave them a turn loose so the halves can
float. The pockets hold the nuts, so the whole bracket tightens
with just a screwdriver on the head side; M3x30s also work, they
just stand about 5 mm proud of the nut face. Roll the bracket on
the arm until the stub groove points straight up and slide a
112 mm stub down through the groove until it sits flush with the
bracket's underside; the funnel mouth in the top face guides it
in. Check the stub points straight up, then tighten the four
bolts evenly. Same rule as the hub: the halves must NOT touch; an
even gap all around means the rods, not the plastic, carry the
preload.

The stub is the vane's hinge, and vertical is the point: a hinge
gravity cannot fight is what lets the rotor start in light wind.
Drop a PTFE washer over each stub onto the bracket's flat top,
then the vane sleeve, notched end up; its lower end rests on the
washer, and that slippery millimeter is the vane's whole thrust
bearing. Then the end cap, open face and wedge DOWN into the
notch, bolts loose; it gets set in step 5. The washer takes all
the running friction; if one ever looks chewed up, pop the cap,
lift the sleeve, and drop a fresh washer on. They cost pennies,
so keep a couple of spares in the toolbox.

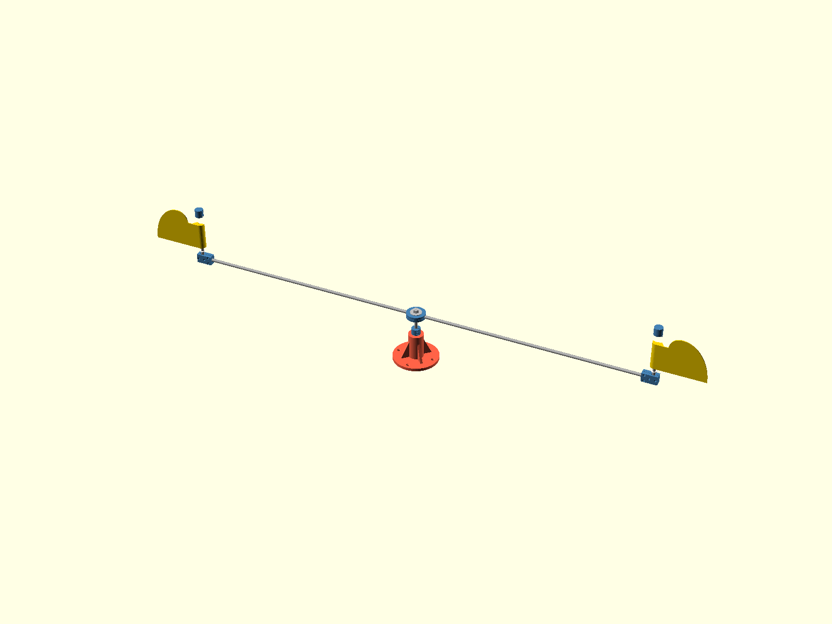
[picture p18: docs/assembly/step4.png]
step 4


## 5. Set the caps, then clamp them

The cap's wedge is the only stop, and the cap is a clamp, so this
step is where the driven-stop angle is chosen. The reference
setting is panel-along-the-arm: hold the flag pointing straight
out along the arm, push the end cap down to leave the sleeve about
a millimeter of vertical play, rotate it until its wedge face just
touches the notch wall on the stopped side, and tighten its two
clamp bolts while holding the angle.

Two things matter, and only the first is checked by eye once: BOTH
flags must stop in the same rotational sense seen from above, or
the torques cancel instead of adding. The keyed ring used to
guarantee that; the adjustable cap trades it for a stop angle you
can move on the water, so check it whenever a cap is re-set. And
the angle itself is now a two-bolt experiment: loosen, rotate,
clamp, watch the machine. The swing arc stays about 90 degrees
wherever the stop points (it is the sleeve notch minus the wedge
width, so changing the ARC is a reprint of two small caps with a
different wedge width, without touching the vanes).

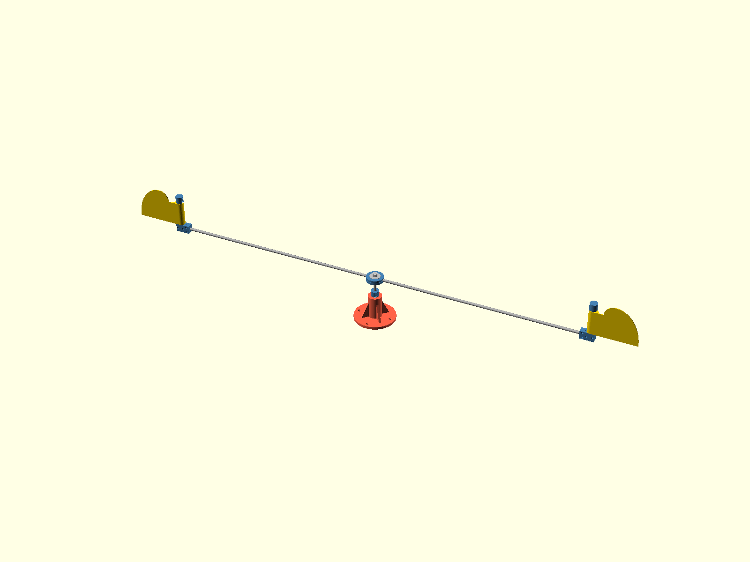
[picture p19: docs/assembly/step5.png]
step 5


## 6. Test

Spin the rotor by hand. It should coast freely on the bearings, and
each vane should clack firmly against its stops with no plastic
rubbing anywhere. In wind, the driven vane presents its face while the
returning vane folds flat, like this:

complete

If it turns stiffly, either a wedge is rubbing its notch floor (the
vane needs its millimeter of end play from step 5) or something is
pressing a rotating face against a static one. Everything here is a
clamp, so any position or angle can be corrected by loosening two
bolts. The one recurring duty: re-torque all the clamp bolts at the
start of each season, and after the first week of running, because
printed plastic relaxes under preload.

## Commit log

2026-07-22 Wind-driven gull scarer: full CAD, tooling, and print-ready STLs
    Printed base with countersunk plank screws and a tower press-fitting
    two 608 bearings, 8 mm aluminum shaft and 60 cm arms held by a printed
    hub, and at each arm tip a flag-style vane whose end-cap pin gives it
    a 120 degree free swing and a hard stop. The swing asymmetry is what
    makes wind torque the rotor; the stop clatter is part of the scaring.
    Tooling follows the starling pattern: design_params.scad as single
    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
    [base.scad, base.stl, bearing_608.scad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]
2026-07-22 Shorter shaft, heavier build, two-sided wedge stops, T hub
    Design revision after review of the first pass:
    - Shaft halved to 150 mm; vanes reshaped to 200x100 so they keep
    their area and still clear the plank by 60 mm.
    - Everything beefed up for years of high wind: thicker base flange,
    9 mm tower walls with the races 55 mm apart, bigger gussets, a
    larger hub with deeper rod sockets, 3 mm vane panels, heavier
    collars and caps.
    - The swing stop is now a 40 degree annular wedge instead of a pin,
    and it sits on BOTH sides of the vane sleeve: a new arm_collar
    part carries the inboard wedge, the end cap the outboard one, so
    every stop impact lands flat on two faces (lib/stop_wedge.s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
    [arm_collar.scad, arm_collar.stl, base.stl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]
2026-07-22 Through-bolt every rod joint; add rendered assembly guide
    The slit clamps and set screws were the weakest link: printed plastic
    gripping smooth aluminum by friction creeps loose over years, and the
    stop impacts twist the caps and collars around the rod. Every rod
    joint is now an M3 through-bolt crossing part and rod, with the rod
    drilled at assembly through the part's own printed hole and a nyloc
    nut in a printed pocket. Collar loses its slit, the end cap its
    self-tapper, the hub its nut slots.
    docs/assembly.md is a six-step guide whose images are build products:
    main_assembly.scad takes -D step=N and regen_all renders
    docs/assembly/step1-5.png, byte-checked by the verify gate like every
    ot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
    [arm_collar.scad, arm_collar.stl, collar.scad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]
2026-07-22 Assembly order: drill every joint at the bench, not on the machine
    Drilling the rotor joints in place was awkward, especially the hub
    over the tower. The guide now follows a bench-first order: the hub,
    shaft, and arms are all blind sockets that bottom out, so the whole
    rotor core is drilled and bolted in a vise before anything meets the
    base. The thrust collar, whose position the bearing stack defines, is
    marked on the machine and drilled at the bench; the stop angles are
    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
    [main_assembly.scad]
2026-07-22 Clamshell hub and wide dual-bolt clamps: no rod is ever drilled
    The hub splits on the vertical plane containing all three rod axes:
    lay the shaft and arms into the grooves, close the other half over
    the registration pegs, and five M5x40 bolts with wide washers clamp
    every joint at once. Contact area is orders of magnitude beyond any
    set screw, the rods stay undrilled where their bending peaks, and a
    0.8 mm face gap (gated) guarantees the preload lands on the rods.
    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
    [arm_collar.scad, arm_collar.stl, collar.scad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]
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2026-07-22 Calibrated fits: bearing pocket 21.95, rod free bore 8.4
    Measured with the printed gauges on the actual bearings and rod stock.
    Regenerated the affected artifacts (base, vane, bearing gauge, assembly
    and step renders) with regen_all; verify passes.
    [base.stl, design_params.scad, vane.stl]
2026-07-22 Uplift retainer: second collar under the bottom bearing
    Nothing previously resisted upward motion of the shaft: the rotor sat
    in its bearings by gravity alone, and a wave slam or gust that unloads
    it could walk the shaft out of the tower. A second plain collar (the
    same printed part as the thrust collar) now clamps boss-up under the
    bottom bearing's inner race with 1 mm of running clearance: it carries
    nothing in normal running, catches the inner race on any uplift, keeps
    the bottom bearing captive, and turns a slipped thrust collar into a
    1 mm drop instead of a rotor on the plank.
    The shaft grows to 172 mm and its tip hangs 20 mm below the base in a
    30 mm hole the user drills in the plank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
    [base.scad, collar.scad, design_params.scad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]
2026-07-23 Hub: drop the corner rounding, square outline
    The halves print lying on their outer face, and there the r6 corner
    rounding survives only along the beam, curling the bed edge under at
    both ends of each half. Print test showed it: two layers of steep
    overhang around each end for a feature that carried no load. The
    outline is now a plain square, so the end walls rise straight from
    the bed.
    [design_params.scad, hub.scad, hub_back.stl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]
2026-07-23 Retainer moves inside the base: cavity, windows, single-bolt collar
    Print test feedback: instead of hanging the retainer below the base
    through a hole in the plank, the bottom bearing moves up 20 mm and
    the retainer lives in a 30 mm cavity inside the tower, open to the
    plank. Two windows in the tower wall, sized between the gussets, give
    a finger and a ball-end hex key access to slide it up and clamp it;
    they are deliberately narrower than the retainer, so once the base is
    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
    [base.scad, base.stl, collar.scad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]
2026-07-23 Retainer set at the bench: flush with the tip, gap gauged at the thrust collar
    Assembly rethink from review: instead of reaching into the base to
    set the retainer, the retainer is clamped to the shaft at the bench,
    flush with the tip (press both against something flat, no measuring).
    The rotor is then turned upside down and the base lowered over the
    shaft until the bottom race rests on the retainer boss, which is the
    uplift catch contact itself. Gauging the THRUST collar 1 mm off the
    top race in that position hands the shaft exactly 1 mm of play, so
    flipped upright the retainer floats 1 mm under the bottom race.
    That kills the tower windows entirely: nothing inside the cavity is
    ever reache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
    [base.scad, base.stl, design_params.scad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]
2026-07-23 Docs: retainer is optional, and fits are per-material
    Field testing says the rotor's weight alone keeps the shaft seated
    in ordinary conditions, so the uplift retainer becomes an optional
    piece. The shaft length is the same either way; without the retainer
    the tip just rides loose in the cavity. The part, the cavity, and
    their geometry checks stay in the design, and the guide gains a
    without-retainer step 3 flow plus a retrofit procedure (base
    unscrewed, retainer set through the open cavity mouth with the card
    gauge). M3 count reads 10 plus one for the retainer if fitted.
    Also records that the calibrated fits are printer, profile and
    filament specific: the PLA prototype's numbers do not tra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
    [main_assembly.scad, retainer.scad]
2026-07-23 Vertical hinge vanes: tip brackets, stub rods, door-style flags
    The alternative low-wind fix: instead of balancing the hanging
    panel, the hinge turns vertical so folding never fights gravity at
    all. Each arm tip gets a printed knuckle (tip_bracket.scad, two wide
    dual-bolt clamps in one block: a horizontal blind socket on the arm,
    a vertical through bore for a 130 mm stub of the same 8 mm stock).
    The existing stack simply stands up the stub: arm collar boss and
    wedge up as the sleeve's thrust seat and lower stop, sleeve, end cap
    wedge down. The vane keeps its sleeve and notches; the panel now
    reaches out horizontally (vane_reach 150) and spans 140 along the
    sleeve, overhanging its top so the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
    [design_params.scad, main_assembly.scad, tip_bracket.scad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]
2026-07-23 ASA calibration: rod snug 8.0, rod free 8.2
    Measured with the gauges printed in ASA with the production profile,
    for the final build. ASA shrinks more than the PLA the prototype was
    calibrated in, so both rod fits come in 0.2 tighter; the bearing
    press pocket measured the same 21.95. Every part with a snug or free
    bore regenerates.
    [arm_collar.stl, collar.stl, design_params.scad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]
2026-07-23 Clamshell tip bracket with M5s, lower stop printed in, arm collar retired
    The bracket becomes two identical halves closing over arm and stub
    like the hub closes over its rods: both rod axes lie in the split
    plane, four M5x40s with wide washers clamp both at once, and with
    the ASA snug a true 8.0 the rods lay in instead of pressing through
    teardrop bores. The half is z-symmetric where it must be and carries
    one peg and one socket placed symmetrically, so it mates with a copy
    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
    [arm_collar.scad, arm_collar.stl, bracket_half.scad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]
2026-07-23 Bracket fin: lower stop integrated at the split plane, halves split into two designs
    Review feedback: the vestigial boss and wedge under the bracket
    looked bad, and so did the wedge's sideways print ramp. Both gone.
    The clamshell now has two half designs, printed two of each: the FIN
    half (pegs, its boss arc, and the lower stop) and the PLAIN half
    (peg sockets, its boss arc). Nothing protrudes below the bracket.
    The lower stop becomes a fin whose contact flank lies exactly IN the
    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
    [bracket_fin_half.scad, bracket_fin_half.stl, bracket_half.scad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]
2026-07-23 Bracket fin: 45-degree facet so every under-surface is self-supporting
    Print review of the fin half (printed outer face down, split face
    up): the fin's contact flank lies flush in the top surface and its
    far flank leans 40 degrees from vertical, both fine, but the outer
    arc curls past the 45-degree lean over its last few degrees near the
    far flank, a sub-millimeter strip that a slicer would flag. A facet
    on the tangent plane 45 degrees off the split replaces that strip,
    so the fin now has no under-surface steeper than the printable lean:
    flush at the top, leaning flank, vertical walls, faceted corner.
    The facet trims only the free-swing end's outer corner, which is the
    soft cushioned contac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
    [tip_bracket.scad]
2026-07-23 Stop ring: the lower stop becomes a keyed part the clamshell traps
    The user was right: the fin-on-the-bracket could not print without
    support. In the halves' print orientation the fin's deepest layers
    are lines anchored only at one edge to the block's top-face wall,
    hanging over the swing pocket; no facet fixes a one-ended bridge.
    The previous facet commit was also geometrically a no-op (a tangent
    plane never cuts its own cylinder).
    The lower stop moves to its own part, stop_ring.scad (print two): a
    D-footed disc whose foot drops into a matching pocket in the bracket
    top and is trapped when the clamshell closes, exactly how the rods
    are trapped. The D flat keys one orientation, so the drive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
    [bracket_fin_half.scad, bracket_fin_half.stl, bracket_peg_half.scad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]
2026-07-23 Slim M3 tip bracket: sized for weight, not for preload
    Review call: the tip brackets ride 620 mm out, so their hardware is
    the one place where bolt mass matters, and M3 preload is plenty for
    a clamp whose only friction duty is gust torsion about the arm (the
    tip's weight and drag ride on rod-in-groove contact, not friction).
    The clamshell drops to four M3x30s with small washers per bracket,
    the body slims from 30 to 24 tall and 52 to 50 long, and the stub
    shortens to 113. Width stays 24 because the stop ring pocket needs
    its side walls. Bolt and peg positions move in to keep every wall
    at the same gates (arm bolts and pegs re-seated clear of the pocket
    and grooves; all clamshell checks reco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
    [bracket_peg_half.stl, bracket_plain_half.stl, design_params.scad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]
2026-07-25 Cap slit out of the flap's swept arc, brackets assemble one piece at a time
    Test print findings at the arm tips, fixed without touching the vane:
    The cap's slit sat opposite the wedge, which parks its nut corners and
    bolt tips (the only things proud of the cap cylinder) square in the arc
    the folding flag's near edge sweeps, so the nuts stopped the fold about
    twenty degrees short. The slit direction is now a shared parameter,
    cap_slit_deg, set 90 degrees from the wedge on the blocked side, and
    geometry_check gates the angular band: hardware at -70..-30 degrees off
    the wedge, flag sweeping 25..190, 55 degrees clear.
    While modeling the band: the flag rim's inner corner passes 12.1 mm
    from the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
    [bracket_peg_half.stl, bracket_plain_half.stl, design_params.scad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]
2026-07-25 Performance gate and a documentation sweep toward 1.0
    scripts/performance_check.py answers the two product questions with
    numbers and holds the line in CI: the rotor self-starts at 1.2 m/s
    (set by the sleeve's thrust-face friction on the stop ring's boss,
    gated at 1.8 so the machine always runs in Beaufort 2), and the
    parasitic-to-driving torque ratio is 0.021, gated at 0.05, so a
    change that adds drag or hinge load fails the build.
    The survival case is a locked rotor holding a flag face-on at 25 m/s
    (a spinning rotor unloads itself, a fouled one cannot). Every load
    path is checked with a safety factor: arm bending at the hub (the
    machine's fuse, SF 1.38 against T5 rod yield), stub bending,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
    [design_params.scad, end_cap.scad, vane.scad]
2026-07-25 Ring replacement never opens the clamshell
    The worn-ring note in step 4 predated the feed-in-from-above
    sequence: a chewed stop ring is replaced by popping the cap and
    lifting sleeve and ring off the stub. Also suggest printing spares;
    the ring is the designated wear part.
2026-07-25 Swing 90: the flag re-arms in time, tuned by the ring fin alone
    Field feel at 120 degrees of swing was a flag that wastes energy
    getting back to work, and the model agrees: after the trailing
    release the swing-back consumes rotor travel that scales with the
    swing angle while the driven-stop window is 180 minus the swing.
    The transit-versus-window comparison is wind independent, and at
    120 it read roughly 120 degrees of transit against a 60 degree
    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
    [design_params.scad, stop_ring.stl]
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2026-07-25 Tri screwed stub tip: tapped rod ends replace clamps, ring fin is the only stop
    The hub's joint idea becomes the tri's design language: every rod
    lands on a printed step and is pulled home by one M5 with a washer
    into a tapped rod end. The stub is tapped both ends: it drops
    through the bracket onto a printed step, screwed from below, so the
    stub-clamp bolt pair is gone and the clamshell only clamps the arm;
    the cap lands on the stub's top face, screwed from above.
    The cap loses the wedge on a field finding: two stop faces never
    land exactly together, one takes every hit anyway. The ring fin is
    now the only stop; the stop-face gate already sizes a single face
    for the full impact, the ring st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
    [tri_assembly.scad, tri_end_cap.scad, tri_params.scad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]
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2026-07-25 Tri washer-jaw hub: one spacer disc, fender washers as steel clamp jaws
    The hub iterated down to its minimum: one printed disc, thinner
    than the rod, with three full-height slots keying the arms at 120
    degrees. The arms stand proud of both faces and two large M8 fender
    washers press onto them from either side, clamped by M8 nylocs on
    the shaft's die-threaded top end. The clamp path is steel washer,
    aluminum rod, steel washer, steel nut, with no plastic in
    compression, so this joint never needs the dual's seasonal
    re-torque. The shaft is die-threaded, never drilled: 8 mm rod is an
    M8 thread blank.
    Also records a correction: the earlier claim that thread at the
    shaft exit fails the storm case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
    [tri_assembly.scad, tri_hub.scad, tri_params.scad]
2026-07-25 Tri hub sandwich variant: two thin half-shells between the washers
    The in-between of the split hub and the slot disc: two identical
    6 mm half-shells (3.6 seat, 2.4 web) cradle the arms over the full
    grip and the fender washers clamp the sandwich. Distributed bearing
    and nothing to rattle, at the price of the webs putting plastic
    back in the clamp path, so a little of the dual's clamp creep
    returns. Same hardware and stations; the scene shows the sandwich,
    the slot disc stays modeled alongside as the no-re-torque
    alternative, and the doc frames the A/B for the bench and the
    water.
    [tri_assembly.scad, tri_hub.scad, tri_params.scad]
2026-07-25 Drop the drawn mast from the tri scene
    The pole under the base kept reading as a stray rod or a bearing
    bug. The taller-mounting ladder step stays in the study and the
    doc as numbers; the scene now sits on the plank level like the
    dual's.
    [tri_assembly.scad, tri_params.scad]
2026-07-25 Tri v0.1 keeps the dual's clamped tip; screwed stub becomes deferred kit work
    Decision from review: the washer-jaw/sandwich hub stays, the tip
    reverts to the dual's clamp design verbatim. Every part outboard of
    the hub comes off the proven dual print files, and the only rod
    prep in the whole machine is the single M8 die pass on the shaft:
    no taps, no drilling. The screwed-stub bracket and wedge-free cap
    stay modeled in cad/tri/ marked as the deferred kit direction, and
    the one-stop field finding is recorded as a candidate for both
    lines after water testing.
    [tri_assembly.scad, tri_end_cap.scad, tri_params.scad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]
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2026-07-29 Arched pennant vane: the tip sweeps from the shoulder to the bottom outer corner
    Field-direction refinement: the straight taper to the top outer
    corner becomes one quarter-ellipse arch from the top inner corner
    (the shoulder at the sleeve top) down to the bottom outer tip,
    tangent to the shoulder where it springs and square to the bottom
    edge at the tip. The swing mechanics only feel how area spreads over
    reach, so the arch moves the face inboard: hinge inertia drops from
    3.8e-4 to 1.5e-4 kg m2 and the re-arm transit improves (100 to 96
    degrees of rotor travel under the rim-honest model), which is the
    binding number; the trailing flag also shows half the edge-on
    silhouette and loses the flap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
    [design_params.scad, film_vane.scad, tri_params.scad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]
2026-07-29 Shorter reach, raised arch, and a slimmed hub clamshell
    The vane trades reach for height: 130 mm reach (was 150) with the
    arch now rising 30 mm above the sleeve top in a quarter circle off
    the shoulder, cresting tangent into the ellipse sweep down to the
    tip. Height is free for the swing mechanics, only the spread over
    reach enters the hinge integrals, so the raised arch buys fold
    moment back near the hinge while the shorter reach sheds tip
    inertia: fold self-start improves 1.40 to 1.35 m/s and the re-arm
    transit drops to about 88 degrees of rotor travel, inside the 90
    degree driven window for the first time. Vane 55 g solid. The
    performance model gains exact area, centroid and inertia integ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
    [design_params.scad, hub_back.stl, hub_front.stl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]
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2026-07-30 Arm diameter is a parameter: arm_rod_d with its own gauged fit
    The two horizontal arms get their own stock knob, arm_rod_d
    (default 8, the shared stock), separate from the shaft and stubs,
    which stay pinned to 8 by the 608 bore and the M8 die pass. The
    hub and bracket arm grooves, the hub disc slots and the tri hub
    seats all cut to a new arm_snug_d, gauged not derived: the rod
    fit gauge grows a second bar off the arm stock whenever the
    diameters differ, and while they match, geometry_check pins
    arm_snug_d to rod_snug_d so the knob cannot drift silently. The
    disc thickness pin moves to arm_rod_d - hub_clamp_gap.
    The performance model follows: arm mass, hub and bracket clamp
    friction radii, t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
    [design_params.scad, hub.scad, hub_disc.scad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]
2026-07-31 The hub is the shell sandwich now; the clamshell is the variant
    The cylinder hub takes over as THE hub, rebuilt as the tri's
    two-piece shell sandwich sized for the dual's two arms: two
    identical thin shells (hub_shell.scad, print two) cradle the arms
    in half-round seats from the boss circle to the rim, and two M8
    nylocs squeeze the stack between fender washers on the shaft's
    die-threaded top. The seats are shallower than half the arm by
    half the clamp gap, so the shells never touch and the preload
    lands on the rods, the clamshell rule. Full-length seats bear
    kindly on the arms and nothing rattles; the price is a little
    plastic back in the clamp path, so the two hub nuts join the
    seasonal re-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
    [design_params.scad, hub.scad, hub_back.scad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]
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2026-08-01 Docs current for v1.1: default build up front, alternatives in one place
    Release-prep sweep, no CAD or script changes. The shell sandwich is
    the hub everywhere the docs speak: the README's closing summary no
    longer calls the hub a clamshell, the arm-diameter note no longer
    mentions the deleted disc grooves, and the short assembly version
    now includes the die jig and treats the retainer as the option it
    is.
    The M5 hub clamshell moves out of the bill of materials into a new
    Alternative versions section at the bottom of the README, joined by
    a pointer to the tri variant, which the README never mentioned at
    all. In the tri concept doc the hub section now leads with the
    shell sandwich as the def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
